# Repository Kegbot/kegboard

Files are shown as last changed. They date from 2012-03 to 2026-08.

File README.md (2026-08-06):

# Kegboard

Kegboard is the kegerator controller firmware from the [Kegbot][kegbot] project.
It reads flow meters, temperature sensors, and auth tokens, drives valves and
relays, and reports pours to a [Kegbot Server][kegbot-server].

This is **Kegboard v4**, a ground-up rewrite for **ESP32** built on
[ESPHome][esphome].

> **Looking for the Arduino version?** The v2/v3 firmware lives on the
> [`arduino`](https://github.com/Kegbot/kegboard/tree/arduino) branch. It is
> feature-frozen and does not speak the same protocol as this one.

**[📖 Documentation](https://docs.kegbot.org/projects/kegboard)** — overview,
operating modes, installation, wiring, configuration, and the protocol specs.
Sources in [`docs/`](docs/).

## What changed, and why

The old Kegboard was a dumb sensor pipe: it streamed raw tick counts over USB
serial, and a host daemon (`kegbot-pycore`) assembled those ticks into pours and
posted them to the server. That meant a cable, a always-on host, and a lost pour
whenever the host was down.

Kegboard v4 is a networked appliance:

- **Pours are assembled on the device.** The board detects the start and end
  of a pour, applies its own calibration, and reports a finished pour with an
  authoritative `volume_ml`.
- **One simple protocol.** Everything is JSON batches to a single endpoint
  (`POST /kegboard-event`), specified in
  [docs/kegboard-event-protocol.md](docs/kegboard-event-protocol.md) with
  normative JSON Schemas. Any server can implement it.
- **Outages are survivable.** Events queue and deliver late with correct
  timestamps — even on a board whose clock never synced — and retries can
  never create a duplicate drink.
- **No API keys to carry around.** An unprovisioned board shows up on the
  server dashboard by name; click allow and it provisions itself.
- **No `kegbot-pycore`, no USB cable.** WiFi and HTTP.
- **It's ESPHome.** Adding a display, a pressure sensor, a second thermometer,
  or a different RFID reader is YAML you write, not a firmware release we ship.

## Configuration

A minimal two-tap board reporting to a server:

```yaml
external_components:
  - source: github://Kegbot/kegboard@main

kegboard:
  id: kb

kegboard_meter:
  - id: flow0
    pin: GPIO4
    meter_number: 0
    total:
      name: Tap 1 Ticks
    pouring:
      name: Tap 1 Pouring

kegboard_reporter:
  reporting_url: !secret kegboard_reporting_url
  meters: [flow0]
```

See `examples/` for complete configs, and `boards/` for pin maps.

### `kegboard`

| Option | Default | Notes |
|---|---|---|
| `serial_number` | `kegboard-<mac>` | Device identity in the protocol. Set explicitly to adopt a replaced board's identity. |

### `kegboard_meter`

| Option | Default | Notes |
|---|---|---|
| `pin` | required | Meter input. Pulled up internally; counts falling edges. |
| `meter_number` | `0` | The protocol's meter number: `(device, meter_number)` identifies a tap server-side. Must be unique per meter (validated at build). The YAML `id` is a config-internal reference and is never reported. |
| `ml_per_tick` | `0.185` | SwissFlow SF800 and clones (~5.4 ticks/mL). The device's calibration is authoritative: reported volume comes from this. |
| `debounce` | `1200us` | Matches the legacy firmware's filter. |
| `idle_timeout` | `10s` | Silence after which a pour is considered finished. |
| `min_pour_ticks` | `3` | Anything shorter is treated as a drip and discarded. |
| `max_pour_duration` | `5min` | Safety cutoff for a stuck meter; `0s` disables. |
| `report_interval` | `250ms` | Throttle for sensor updates during a pour. |
| `series_resolution` | `100ms` | Bucket width for the diagnostic tick series; `0s` disables. |

Optional entities: `total`, `volume`, `flow_rate`, `pouring`.
Triggers: `on_pour_start`, `on_pour_end` (with `ticks`, `volume_ml`, `duration_ms`).
Actions: `kegboard_meter.reset_total`, `.end_pour`, `.set_calibration`.

### `kegboard_reporter`

Speaks the [Kegboard Event Protocol](docs/kegboard-event-protocol.md).

| Option | Default | Notes |
|---|---|---|
| `reporting_url` | required | Full URL, path included, e.g. `https://kegbot.example.com/api/kegboard-event`. No credential is configured — the device provisions its own bearer token by pairing via the server dashboard, and it persists in flash. |
| `meters` | `[]` | Meters whose pours are reported. |
| `relays` | `[]` | The device's numbered relays: `relay_number:` plus `relay:`. Reported in the `status` inventory, and the targets of server grants. |
| `thermo_sensors` | `[]` | `sensor:`/`name:` pairs; any ESPHome sensor works. |
| `heartbeat_interval` | `60s` | Status event cadence; also bounds worst-case command latency. |
| `pour_update_interval` | `1s` | Live `pour_update` cadence; `0s` disables. |
| `retry_interval` | `30s` | Base for exponential backoff, capped at 5 min. |

Optional diagnostic entities: `queue_depth`, `dropped`. A non-zero `dropped`
means events were lost and is worth alerting on.

### `kegboard_auth`

Applies [authenticated pouring](docs/authenticated-pouring.md):
server-decided grants driving valve relays and tagging pours for server-side
attribution. Requires a `kegboard_reporter`. (Serverless installs can gate
valves with plain ESPHome automations on the reader triggers instead.)

| Option | Default | Notes |
|---|---|---|
| `offline_policy` | `deny` | Token presented while the server is unreachable: `deny` (signal refusal), or `guest` (stay silent; pours proceed as guest pours). Neither opens valves. |
| `max_grant_duration` | `5min` | Device-side clamp on server-issued grants: the final bound on valve-open time. |

Actions: `kegboard_auth.token_attached` / `.token_detached` (`device`,
`token`), `.revoke`. Condition: `.is_authorized`. Triggers: `on_authorized`
(`auth_device`, `token`), `on_denied` (`reason`), `on_revoked`. Optional
entities: `authorized`.

### `kegboard_onewire`

iButton presence on a 1-Wire bus — ESPHome's `one_wire` enumerates devices but
has no arrive/leave events. Triggers `on_token_attached` and
`on_token_detached` with the ROM code as hex.

`max_missed_searches` (default `4`) is how many consecutive misses before a
detach is reported. A held iButton makes intermittent contact, so reporting on
the first miss would make it flap several times a second.

### Relays and buzzer

`packages/relays.yaml` and `packages/buzzer.yaml` are plain YAML over stock
components. The relay watchdog is worth keeping from the AVR firmware: a relay
left on is usually a valve held open, so each one switches itself off
`relay_watchdog_timeout` (default `10s`) after turning on. On grant-driven
relays, set it longer than `max_grant_duration` (the grant clamp is their
bound) or the watchdog closes the valve mid-grant.

## Repository layout

```
components/     ESPHome external components (this repo is the component source)
  kegboard/     Hub component + the framework-agnostic core (see CORE.md)
  kegboard_meter/     Flow meter and pour detection
  kegboard_reporter/  Event protocol client (batching, pairing, commands)
  kegboard_auth/      Per-meter authorization
  kegboard_onewire/   iButton presence
packages/       Composable YAML users include
boards/         Pin maps per target board
docs/           Manual + protocol specifications
schemas/        Normative JSON Schemas for the protocol
examples/       Worked configurations
tests/core/     Host unit tests -- plain g++, no hardware, no toolchain
script/         CI helpers
```

## Development

Host unit tests for the core logic need nothing but a C++ compiler:

```console
$ make -C tests/core
$ make -C tests/core STRICT=1   # warnings as errors, as CI runs it
```

Build output is scoped by OS and architecture (`build/Darwin-arm64/`, etc.), so
a checkout shared between a host and a container or VM won't hand one
platform's binaries to the other.

Formatting and lint mirror ESPHome's own conventions, since these components
compile into ESPHome's tree:

```console
$ pip install pre-commit && pre-commit install
$ pre-commit run --all-files
```

The manual is a Sphinx project in `docs/`, published at
[docs.kegbot.org/projects/kegboard](https://docs.kegbot.org/projects/kegboard).
Its toolchain is managed by [uv](https://docs.astral.sh/uv/), synced
automatically on first use:

```console
$ make -C docs html          # output in docs/_build/html/
$ make -C docs livehtml      # live-rebuild server while editing
```

## Simulator

`tools/kegboard-sim.py` is a TUI kegboard for developing receivers without
hardware. It speaks the full protocol — pairing, batching, `age_ms`,
commands, dedup — and validates every outgoing batch against the schemas, so
it cannot teach a server the wrong protocol.

```console
$ uv run tools/kegboard-sim.py http://localhost:8000/kegboard-event
```

Single keys drive it: pour a beer (with live `pour_update`s), toggle
temperature logging, present preset tokens (including an unknown fob and a
presence-style iButton), kill the heartbeat so your server's liveness check
can notice, go offline to build a backlog that delivers late with correct
ages, replay the last batch verbatim to exercise dedup, send an
unknown event type, and reboot to reset `boot_id`.

## Debugging

The reporter logs one line per delivery at `DEBUG` (status, event count,
bytes). To see the actual protocol traffic — every request and response body,
including `pour_update`s while beer is flowing — raise its log level to
`VERY_VERBOSE`:

```yaml
logger:
  logs:
    kegboard_reporter: VERY_VERBOSE
```

Then attach with `esphome logs <config>.yaml`. Two notes:

- `VERY_VERBOSE` lines are compiled out at default log levels, so production
  builds pay nothing for this machinery.
- The logger truncates lines to its buffer (default 512 bytes); a full batch
  body will clip. Add `logger: { tx_buffer_size: 2048 }` if that bites.

## Hardware notes

**ESP32 GPIOs are not 5 V tolerant.** Most beer flow meters are open-collector
hall-effect sensors, which are safe on a 3.3 V pull-up because they only ever
pull the line to ground. Meters with a push-pull 5 V output will damage the
ESP32 and need a level shifter or divider. Check your meter before wiring it.

## History

Kegboard was created in 2004 and has received several major updates over the
years:

- **v1 (2004)** — PIC16-based, written in the JAL programming language.
- **v2 (~2009)** — rewritten for Arduino, introducing the KBSP serial
  protocol.
- **v3 (2014)** — the Kegboard Pro Mini, a fully-assembled Arduino-based
  board.
- **v4 (2026)** — this ground-up ESP32 rewrite on ESPHome.

## License and copyright

Kegboard v4 is offered under the **MIT** license, matching the rest of the
Kegbot project; see `LICENSE.txt`.

Two notes on what that does and doesn't cover:

- **Built firmware images are GPLv3.** ESPHome's C++ runtime is GPLv3, and a
  compiled Kegboard image links against it. MIT is GPL-compatible, so this is
  fine and is how ESPHome external components normally work — but if you
  distribute binaries, you are distributing GPLv3 binaries. The source in this
  repository remains MIT and is reusable as such.
- **The `arduino` branch is still GPLv2-or-later.** The legacy AVR firmware was
  written under that license and had outside contributors; nothing here
  relicenses it.

Copyright 2003-2026 The Kegbot Project Contributors <info@kegbot.org>

[kegbot]: https://kegbot.org/
[kegbot-server]: https://github.com/Kegbot/kegbot-server
[esphome]: https://esphome.io/

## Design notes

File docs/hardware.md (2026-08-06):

# Hardware & Wiring

Kegboard v4 targets generic ESP32 devkits. There is no custom PCB (yet); the
legacy kegboard-mini/mega/coaster boards ran the AVR firmware and live on the
[`arduino` branch](https://github.com/Kegbot/kegboard/tree/arduino).

## Supported boards

| Board package | Chip | Notes |
|---|---|---|
| `boards/esp32-s3-devkitc-1.yaml` | ESP32-S3 | **Reference target.** Native USB (no adapter to flash), ample GPIO, PSRAM headroom. |
| `boards/esp32-devkit.yaml` | ESP32 (WROOM-32) | What most people already have in a drawer. |
| `boards/esp32-c6-devkitc-1.yaml` | ESP32-C6 | Forward-looking: WiFi 6, Thread/Zigbee radios. |

Other ESPHome-supported ESP32 variants work; write your own board package
with the same substitution names.

## Pin maps

Defined as substitutions in each board package; override them in your config
to relocate a peripheral.

| Substitution | S3 | Classic | C6 | Used by |
|---|---|---|---|---|
| `meter0_pin`–`meter3_pin` | 4–7 | 4, 5, 13, 14 | 4–7 | Flow meters |
| `onewire_pin` | 15 | 16 | 10 | Thermo 1-Wire bus |
| `relay0_pin`, `relay1_pin` | 16, 17 | 17, 18 | 11, 18 | Relays |
| `buzzer_pin` | 18 | 19 | 19 | Piezo buzzer |
| `led0_pin`, `led1_pin` | 8, 9 | 21, 22 | 20, 21 | Flow LEDs |
| `rfid_rx_pin` | 44 | 23 | 22 | RFID reader UART |
| `onewire_auth_pin` | 21 | 25 | 23 | iButton 1-Wire bus |

The maps avoid each chip's landmines: strapping pins, flash/PSRAM pins,
native-USB pins, and (on the classic ESP32) GPIO 34–39, which are input-only
with no internal pull-ups and so cannot bias an open-collector meter.

## Flow meters

Kegboard supports open-collector meters — typically hall-effect sensors that
pulse once per fixed volume as liquid passes. Meter inputs use the internal
pull-up and count falling edges; wire the meter's output straight to the pin,
its ground to ground.

> **ESP32 GPIOs are not 5 V tolerant.** Open-collector meters are safe on a
> 3.3 V pull-up even when powered from 5 V, because they only ever pull the
> line to ground. Meters with a push-pull 5 V output will damage the ESP32
> and need a level shifter or divider. Check your meter before wiring it.

The default calibration (`ml_per_tick: 0.185`, ~5.4 ticks/mL) matches the
SwissFlow SF800 and its clones. Other meters work; set `ml_per_tick`
accordingly (a Vision 2000 is ~2200 ticks/L → `0.4545`).

## Temperature sensors

DS18B20/DS18S20 sensors on the `onewire_pin` bus, via ESPHome's `one_wire`
and `dallas_temp`. Any number of sensors on one bus; each needs the usual
4.7 kΩ pull-up to 3.3 V (many breakout probes include it).

## Authentication readers

- **125 kHz RFID:** RDM6300-class readers (the ID-12 lineage) on
  `rfid_rx_pin` via UART at 9600 baud, using ESPHome's `rdm6300`. TX-only —
  nothing is wired back to the reader.
- **iButton:** a second 1-Wire bus on `onewire_auth_pin`, read by
  `kegboard_onewire`. Kept separate from the thermo bus so a wet hand stays
  away from the keg sensors.
- **Anything else:** any ESPHome reader (`wiegand`, `pn532`, `rc522`, ...)
  can feed `kegboard_auth` — see
  [extending](developer-notes.md#extending-a-board).

## Relays and valves

`packages/relays.yaml` defines two GPIO relay outputs, each with a watchdog
that switches it off `relay_watchdog_timeout` (default 10 s) after it turns
on — see the package's notes before putting a grant-driven valve on one.
Use a relay module rated for logic-level (3.3 V) input, or a
transistor driver. What's downstream is usually a solenoid valve; give it its
own supply and a flyback diode if the module lacks one.

## Buzzer and LEDs

A **passive** piezo on `buzzer_pin` plays the legacy Kegboard melodies
(`packages/buzzer.yaml`); an active buzzer generates its own tone and will
ignore them. Flow LEDs are ordinary GPIO LEDs with resistors, wired per the
pin map and driven from `on_pour_start`/`on_pour_end` automations.

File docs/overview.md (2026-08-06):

# Kegboard Overview

## What is a Kegboard?

*Kegboard* is the controller board in a [Kegbot](https://kegbot.org/) system.
It's the device that monitors flow meters and publishes this data to a system
like [Kegbot Backend](https://github.com/kegbot/kegbot-backend).

A kegboard can also monitor additional, optional accessories like temperature sensors
and OneWire-based authentication devices; and it can drive valves,
relays, and buzzers.

An open source Kegboard project has existed since around 2005. Today, it is
built for esp32-based devices, and leverages the [ESPHome](https://esphome.io/)
framework.

You can flash this firmware to a device and use it in standalone mode, or
point it at a [Kegbot Server](https://github.com/Kegbot/kegbot-server) instance
for full functionality.

## Features

- **Flow sensing.** Any number of meters, limited only by GPIO. Pour
  detection runs on the device: start, end, volume, flow rate, and a
  diagnostic tick time series per pour.
- **On-device calibration.** `ml_per_tick` lives on the board; reported
  volumes are authoritative.
- **Temperature sensing.** DS18B20/DS18S20 sensors on a 1-Wire bus, any
  number of them, via ESPHome's stock `dallas_temp`.
- **Authentication.** 125 kHz RFID readers and iButtons out of the box; any
  reader ESPHome supports can feed the auth component.
- **Authenticated pouring.** Server-decided grants drive valve relays and
  pour attribution. See
  [Authenticated Pouring](authenticated-pouring.md).
- **Relay control with watchdog.** Each relay switches itself off after a
  timeout, so a crashed controller never leaves a valve open; grant-held
  relays are bounded by the grant clamp instead.
- **Buzzer.** The classic Kegboard melodies, transcribed from the AVR
  firmware.
- **Outage-proof reporting.** Events queue on the device and deliver late
  with correct timestamps; retries can never create a duplicate drink.
- **Dashboard pairing.** No API keys: an unprovisioned board appears on the
  server dashboard by name and provisions itself when approved.
- **Home Assistant, free.** Every meter, sensor, and relay is an ESPHome
  entity; a server is optional.
- **Open protocol.** Everything is JSON to a single HTTP endpoint, specified
  in the [Kegboard Event Protocol](kegboard-event-protocol.md) with normative
  schemas. Any server can implement it.

Everything is optional except a meter. A board with no thermo sensor, no
reader, and no server still meters pours.

## Requirements

- **An ESP32 board.** Any ESPHome-supported variant works; tested pin maps
  ship for the ESP32-S3-DevKitC-1 (reference), the classic ESP32 DevKitC, and
  the ESP32-C6-DevKitC-1. See [Hardware & Wiring](hardware.md).
- **Flow meters.** Open-collector hall-effect meters such as the SwissFlow
  SF800. **ESP32 GPIOs are not 5 V tolerant** — see the
  [hardware notes](hardware.md#flow-meters).
- **WiFi.**
- **ESPHome** to build and flash, until prebuilt binaries ship. See
  [Installation](installation.md).
- Optionally, a **[Kegbot Server](https://github.com/Kegbot/kegbot-server)**
  (or anything else implementing the event protocol) to record drinks.

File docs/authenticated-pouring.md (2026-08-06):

# Authenticated Pouring

How a token presented at a Kegboard becomes an open valve and an attributed
pour. This document specifies the interaction between device and server; the
message envelopes it uses (`token` events, commands, `command_result`) are
defined in the main protocol doc.

## 1. Background

A Kegboard install always has flow meters on its beer lines: every pour is
measured, whether or not anyone is identified. Many installs add more, per
tap: a solenoid valve on a relay, so beer only flows for someone
authorized, and a token reader nearby (RFID, iButton, ...) to identify who
that is. Others have no valves at all — anyone can pour at any time, and
authentication only decides who a pour is attributed to.

**Everything in this document is optional.** A monitoring-only Kegboard —
just meters, no readers, no valves — needs none of it: it simply reports
guest pours, and its config never mentions authentication at all.

A presented token means something — which user, which taps, how much — and
the token→user database that answers this can be large. It lives on the
server; the valves and the pour detection live on the device. This doc
defines who decides what, and how the two sides stay simple.

## 2. Summary

- A **pour** is metered flow, reported to the server as an event
  (main doc §5.1) — authenticated or not.
- A **grant** is permission to pour. The server creates one with an
  `authorize` command, naming the meters it covers, the relays (valves) it
  opens, and its limits: max volume, max total time, max idle time. One
  active grant per meter.
- Presenting a physical auth token sends a `token` event to the server.
  In response, the server decides whether to grant access (`authorize`
  command), opening any relevant valves; or to deny it (`deny` command).
- Pours are tagged with the covering grant's id; the server maps that to a
  user. **Identity never reaches the device.**
- A grant ends when a limit is hit, its token detaches, the server revokes
  it, or a newer grant takes its meters. Every ending is reported as a
  `grant_end` event with its reason.
- Server unreachable? A configured offline policy (§6) decides whether the
  user is signaled a refusal — either way, nothing opens, and the queued
  `token` event preserves the audit trail.

The rest of this doc unpacks each of these.

## 3. Authorization modes

An install is either authenticated or open:

| Mode | Who decides | Needs server online? | Use case |
|---|---|---|---|
| authenticated (`kegboard_auth` configured) | Server, per token presentment | Yes (with a configurable offline fallback) | Gated or attributed taps. Scales to any token database; policy lives in one place. |
| `open` (no auth component) | Nobody — no gating | No | Meters-only installs, no valves. Every pour is a guest pour. |

Authorization always means the server decides. A serverless install that
wants token-driven valves can wire the reader triggers to relay switches
with plain ESPHome automations — outside this protocol entirely.

The device is **stateless about policy**: it holds no token database and
no meter↔relay map — only the currently active grant(s), each of which
arrives naming the meters it covers and the relays it opens (see main doc
§7.1). The meter↔relay association is backend configuration, owned in
exactly one place: the server composes each grant's sets from it, and the
device applies them verbatim.

## 4. The core flow

1. **Token presented.** The reader reports a token; the device emits a
   `token` event with `action: "attached"` — always a question for the
   server. The device flushes the batch immediately.
2. **Server decides.** The server looks up the token, applies whatever
   policy it likes (user standing, keg access, time of day), and responds —
   in the same HTTP response — with an `authorize` or a `deny` command.
   Servers SHOULD always answer a decision-requesting token event with one
   of the two.
3. **Device acts.** On `authorize`, the device opens the relays named in
   the grant, tags subsequent pours on the granted meters with the
   grant, and acknowledges with a `command_result` event. On `deny`, the
   tap stays closed and the device SHOULD signal the user (e.g. a refusal
   tone). If the response carries neither — a server bug, defensively —
   the device treats the presentment as denied, without the user signal.
4. **Grant ends** by whichever comes first: token detach (presence
   readers), any of the grant's limits — volume poured, total time, idle
   time — being reached, or a server `deauthorize` command. The device
   closes the valve, ends any in-flight pour (still tagged with the
   departing grant), clears the grant, and reports a `grant_end` event
   naming the reason (main doc §5.7), so the server never has to guess
   why a tap went cold.

Identity never travels down. The server attributes the resulting pours
itself, from each pour's `grant_id` — the server's own identifier for the
grant (main doc §5.1, §7.1). The device acts on tokens and grants; it
never knows who a user is.

Authorization latency is one HTTP round trip, because the decision rides the
response to the token event itself:

```
reader              device                                server
  |                   |                                     |
  | token 0089f2c4    |                                     |
  |------------------>| POST /kegboard-event                |
  |                   |   [token attached] ---------------->|
  |                   |                                     | lookup, policy
  |                   |        200 {commands:[authorize]}   |
  |                   |<------------------------------------|
  |                   | open valve(s), record grant         |
  |                   |                                     |
  |                   | ...pour happens...                  |
  |                   | POST [pour grant_id=g_1,            |
  |                   |       command_result ok] ---------->|
```

## 5. Commands

The three commands this flow uses are fully specified in the main protocol
doc (§7.1–7.3); this section describes only their role in the flow.

- **`authorize`** carries exactly one grant: a server-assigned id, the
  meters it covers and the relays it opens (if any). The server composes
  these sets from its own meter and relay configuration, and any limits. The device
  applies it verbatim: relays open, and pours on the granted meters are
  tagged with the grant, until a limit (volume, total time, idle time) or
  the device's own clamp ends it. Several grants at once — different
  taps, different policy — are simply several `authorize` commands in
  one response.
- **`deny`** is the explicit refusal: the device signals the user, and no
  state changes.
- **`deauthorize`** is a server-initiated cutoff, revoking grants by
  id — an admin button, a policy engine, an emergency stop. Detach and
  the grant's own limits do the same thing device-side without a
  command.

## 6. Offline behavior

The decision-maker being remote means presentment can race an outage. The
device applies a configured `offline_policy` when a token event cannot be
delivered (network error / 5xx / no response before a short timeout,
suggested 5 s):

| `offline_policy` | Behavior |
|---|---|
| `deny` (default) | Tap stays closed; the device signals refusal. Correct for installs where gating is the point. |
| `guest` | **Nothing opens and nothing is granted** — the only difference from `deny` is that the user is not signaled a refusal. Pours proceed as ordinary guest pours (a meter without a valve meters regardless), and the queued `token` event reaches the server later, preserving the audit trail. Opening valves offline may be revisited later; for now an offline server never results in an opened valve. |

Note what is deliberately absent: a device-side token cache. Caching
assignments would reintroduce the state this design removes and creates
stale-revocation problems.

## 7. Multi-meter, multi-user

Grants are per meter, so a two-tap device can simultaneously have Alice on
meter 0 and Bob on meter 1:

- Alice presents; the server responds
  `authorize {grant_id: "g_1", meter_numbers: [0], relay_numbers: [0], ...}`,
  recording `g_1` as Alice's.
- Bob presents; the server responds
  `authorize {grant_id: "g_2", meter_numbers: [1], relay_numbers: [1], ...}`,
  recording `g_2` as Bob's.
- Each meter's pours arrive tagged with their own grant's `grant_id`, so
  the server attributes meter 0's pours to Alice and meter 1's to Bob.
  Detach, limits, and `deauthorize` affect only their own grant's meters.

Which meter a presentment maps to is **server policy**, not protocol. The
`token` event tells the server which reader saw the token (`auth_device`);
an install with one reader per tap can name readers accordingly (e.g.
`core.rfid.0`) and the server maps reader → meter. An install with one
shared reader can grant all meters, or apply fancier policy (the user's
reserved tap, the tap with their keg on it). The protocol only carries the
outcome: each grant's `meter_numbers` and `relay_numbers`.

## 8. Grant and pour corner cases

Every way a pour and a grant can interact, and the rule for each. Two
principles cover them all:

- **Attribution is decided when the pour ends.** The pour is tagged
  (`auth_device`, `auth_token`, `grant_id` — main doc §5.1) with the grant
  covering its meter at that moment, in full. The server resolves the user
  from `grant_id` — pinned to its own authorization decision, so a
  late-delivered pour attributes correctly even if the token was reassigned
  in the meantime.
- **Limit accounting is decided as flow is observed.** Flow counts toward
  the grant covering the meter at the moment it flows — toward its
  `max_volume_ml`, and resetting its `max_idle_ms` — and is never
  retroactive.

Where the two disagree (case 2 below), that is deliberate: the rules stay
simple, and the mismatch is confined to a corner. In general this catalog
favors the simple implementation over the clever one, accepting that a
handful of corner cases do slightly surprising things.

1. **Pour with no grant.** An unauthenticated guest pour: no auth fields
   at all. This is every pour in `open` mode, and any pour on a meter
   nobody has authorized — installs without valves meter everything, all
   the time.
2. **Grant arrives mid-pour: it adopts the pour.** The pour keeps its
   `pour_id` and, at its end, is attributed to the grant **in full**,
   including the volume poured before the grant arrived. This is the
   headline corner case on valve-less installs: someone starts pouring,
   realizes they forgot to authenticate, and keys in mid-glass — the whole
   glass lands on their tab. Per the second principle, the pre-grant
   volume does *not* count toward the grant's limits. Adoption is a
   single, clearly marked policy point in the firmware, so it can become
   "split into a new pour" later without disturbing anything else.
3. **Grant replaces another mid-pour: the pour splits.** The in-flight
   pour ends immediately, tagged with the departing grant; flow that
   continues opens a new pour (fresh `pour_id`) under the new grant. Pour
   boundaries always align with authorization boundaries, so consecutive
   drinkers never share a pour record.
4. **Grant updated (same `grant_id`) mid-pour: nothing happens.** It is
   the same grant; the pour continues under it, counters intact.
5. **Grant ends mid-pour** — limit reached, token detached, `deauthorize`:
   the pour ends first, tagged with the grant, and its event precedes the
   `grant_end` (main doc §5.7). Flow that continues — after the valve
   closes, or on a meter that never had one — is case 1 again: a new,
   unauthenticated guest pour.

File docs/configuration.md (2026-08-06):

# Configuration Reference

Kegboard is configured in ESPHome YAML. This chapter covers the Kegboard
components; everything else (WiFi, sensors, displays, automations) is stock
ESPHome — see [esphome.io](https://esphome.io/). `examples/` has complete
configs; `packages/` has the composable pieces.

```yaml
external_components:
  - source: github://Kegbot/kegboard@main
```

## `kegboard`

The hub. Required by every other component.

| Option | Default | Notes |
|---|---|---|
| `serial_number` | `kegboard-<mac>` | Device identity in the protocol. Set explicitly to adopt a replaced board's identity. |

## `kegboard_meter`

One entry per flow meter.

```yaml
kegboard_meter:
  - id: flow0
    pin: GPIO4
    meter_number: 0
    total:
      name: Tap 1 Ticks
    pouring:
      name: Tap 1 Pouring
```

| Option | Default | Notes |
|---|---|---|
| `pin` | required | Meter input. Pulled up internally; counts falling edges. |
| `meter_number` | `0` | The protocol's meter number: `(device, meter_number)` identifies a tap server-side. Must be unique per meter (validated at build). The YAML `id` is a config-internal reference and is never reported. |
| `ml_per_tick` | `0.185` | SwissFlow SF800 and clones (~5.4 ticks/mL). The device's calibration is authoritative: reported volume comes from this. |
| `debounce` | `1200us` | Matches the legacy firmware's filter. |
| `idle_timeout` | `10s` | Silence after which a pour is considered finished. |
| `min_pour_ticks` | `3` | Anything shorter is treated as a drip and discarded. |
| `max_pour_duration` | `5min` | Safety cutoff for a stuck meter; `0s` disables. |
| `report_interval` | `250ms` | Throttle for sensor updates during a pour. |
| `series_resolution` | `100ms` | Bucket width for the diagnostic tick series; `0s` disables. |

Optional entities: `total`, `volume`, `flow_rate`, `pouring`.
Triggers: `on_pour_start`, `on_pour_end` (with `ticks`, `volume_ml`,
`duration_ms`).
Actions: `kegboard_meter.reset_total`, `.end_pour`, `.set_calibration`.

## `kegboard_reporter`

Speaks the [Kegboard Event Protocol](kegboard-event-protocol.md) to a server.

| Option | Default | Notes |
|---|---|---|
| `reporting_url` | required | Full URL, path included, e.g. `https://kegbot.example.com/api/kegboard-event`. No credential is configured — the device provisions its own bearer token by pairing via the server dashboard, and it persists in flash. |
| `meters` | `[]` | Meters whose pours are reported. |
| `relays` | `[]` | The device's numbered relays: `relay_number:` plus `relay:` (the relay to drive, e.g. from `packages/relays.yaml`). Reported in the `status` inventory, and the targets of server grants (and of `set_relay`, once that reserved command is specified). |
| `thermo_sensors` | `[]` | `sensor:`/`name:` pairs; any ESPHome sensor works. |
| `heartbeat_interval` | `60s` | Status event cadence; also bounds worst-case command latency. |
| `pour_update_interval` | `1s` | Live `pour_update` cadence; `0s` disables. |
| `retry_interval` | `30s` | Base for exponential backoff, capped at 5 min. |

Optional diagnostic entities: `queue_depth`, `dropped`. A non-zero `dropped`
means events were lost and is worth alerting on.

## `kegboard_auth`

Applies [authenticated pouring](authenticated-pouring.md): server-decided
grants driving valve relays and tagging pours for server-side attribution.
Requires a `kegboard_reporter`. (Serverless installs can gate valves with
plain ESPHome automations on the reader triggers instead.)

| Option | Default | Notes |
|---|---|---|
| `offline_policy` | `deny` | Token presented while the server is unreachable: `deny` (signal refusal), or `guest` (stay silent; pours proceed as guest pours). Neither opens valves. |
| `max_grant_duration` | `5min` | Device-side clamp on server-issued grants: the final bound on valve-open time. |

Actions: `kegboard_auth.token_attached` / `.token_detached` (`device`,
`token`), `.revoke`. Condition: `.is_authorized`. Triggers: `on_authorized`
(`auth_device`, `token`), `on_denied` (`reason`), `on_revoked`. Optional
entities: `authorized`.

Readers feed it through the actions — see `examples/kegbot-full.yaml` for
RFID and iButton wiring.

## `kegboard_onewire`

iButton presence on a 1-Wire bus — ESPHome's `one_wire` enumerates devices
but has no arrive/leave events. Triggers `on_token_attached` and
`on_token_detached` with the ROM code as hex.

| Option | Default | Notes |
|---|---|---|
| `one_wire_id` | auto | The bus to poll; bound automatically when exactly one `one_wire` bus exists, required with several. Use a bus separate from the thermo sensors. |
| `update_interval` | `1s` | Poll cadence. |
| `max_missed_searches` | `4` | Consecutive misses before a detach is reported. A held iButton makes intermittent contact; reporting on the first miss would flap several times a second. |

## Packages

Plain YAML over stock components; include what you have.

| Package | Provides |
|---|---|
| `packages/base.yaml` | WiFi + fallback AP, OTA, logging, native API, SNTP time, HTTP client. Expects `name` and `friendly_name` substitutions. |
| `packages/relays.yaml` | Two GPIO relays, each with a watchdog: auto-off after `relay_watchdog_timeout` from the on-edge (default `10s`, `0s` disables). On grant-driven relays set it longer than `max_grant_duration` — the grant clamp is their bound — or the watchdog closes the valve mid-grant. |
| `packages/buzzer.yaml` | Passive piezo via `rtttl`, with the legacy boot/auth/ping melodies as scripts. |
| `boards/*.yaml` | Chip selection + pin-map substitutions. See [Hardware & Wiring](hardware.md). |

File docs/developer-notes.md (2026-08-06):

# Developer Notes

## Repository layout

```
components/     ESPHome external components (this repo is the component source)
  kegboard/     Hub component + the framework-agnostic core (see CORE.md)
  kegboard_meter/     Flow meter and pour detection
  kegboard_reporter/  Event protocol client (batching, pairing, commands)
  kegboard_auth/      Per-meter authorization
  kegboard_onewire/   iButton presence
packages/       Composable YAML users include
boards/         Pin maps per target board
docs/           This manual + protocol specifications
schemas/        Normative JSON Schemas for the protocol
examples/       Worked configurations
tests/core/     Host unit tests — plain g++, no hardware, no toolchain
tools/          kegboard-sim, the TUI simulator
script/         CI helpers
```

## Building and testing

Host unit tests for the core logic need nothing but a C++ compiler:

```console
$ make -C tests/core
$ make -C tests/core STRICT=1   # warnings as errors, as CI runs it
```

Firmware builds are plain ESPHome:

```console
$ esphome compile examples/kegbot-2tap.yaml
```

Formatting and lint mirror ESPHome's conventions (clang-format, ruff,
yamllint), since these components compile into ESPHome's tree:

```console
$ pip install pre-commit && pre-commit install
$ pre-commit run --all-files
```

## Hacking on the core

The rules, enforced by CI (`script/check-core-purity.py`):

1. Core files (`components/kegboard/*.cpp/h` in the `kbcore` namespace)
   include only the C++ standard library — no ESPHome, Arduino, or ESP-IDF
   headers.
2. No I/O, no clocks, no timers; time is passed in as arguments.
3. Every core file has host tests in `tests/core/`.

This is what keeps pour detection, the grant table, and the queue-and-retry
path testable in milliseconds without flashing a board — and what keeps the
ESPHome components thin enough to port away from ESPHome if that ever becomes
necessary. Details in
[`components/kegboard/CORE.md`](https://github.com/Kegbot/kegboard/blob/main/components/kegboard/CORE.md).

`script/check-events-schema.py` keeps the C++ event serializers and the JSON
Schemas in agreement.

## Extending a board

Most extensions are YAML, not firmware:

- **More taps:** another `kegboard_meter` entry with a fresh `meter_number`.
- **A different reader:** any ESPHome reader component whose trigger calls
  `kegboard_auth.token_attached` with a `device` name and token string. The
  string must match how the token is registered server-side — log the first
  scan and register that exact value. `examples/kegbot-full.yaml` shows RFID
  (`rdm6300`) and iButton (`kegboard_onewire`).
- **Displays, pressure sensors, more relays, anything ESPHome supports:**
  stock components alongside the Kegboard ones; `on_pour_*` triggers and the
  `pouring`/`authorized` entities are the integration points.

## The simulator

`tools/kegboard-sim.py` is a TUI kegboard for developing receivers without
hardware. It speaks the full protocol — pairing, batching, `age_ms`,
commands, dedup — and validates every outgoing batch against the schemas, so
it cannot teach a server the wrong protocol.

```console
$ uv run tools/kegboard-sim.py http://localhost:8000/kegboard-event
```

Single keys pour a beer (with live `pour_update`s), toggle temperature
logging, present preset tokens, kill the heartbeat, go offline to build a
backlog that delivers late, replay the last batch to exercise dedup, send an
unknown event type, and reboot to reset `boot_id`.

## Protocol traffic logging

The reporter logs one line per delivery at `DEBUG`. For full request and
response bodies:

```yaml
logger:
  logs:
    kegboard_reporter: VERY_VERBOSE
```

`VERY_VERBOSE` lines are compiled out at default log levels, so production
builds pay nothing. The logger truncates lines to its buffer (default 512
bytes); add `logger: { tx_buffer_size: 2048 }` if a batch body clips.

## Cutting a release

The canonical firmware version is `KEGBOARD_VERSION` in
`components/kegboard/kegboard.cpp`; `docs/conf.py` and `packages/base.yaml`
mirror it and must always agree. Don't edit them by hand — release with:

```console
$ script/bump.py --dry-run   # preview
$ script/bump.py             # 4.0.1 -> 4.0.2; a -pre/-dev suffix is dropped
$ script/bump.py 4.1.0       # or pick the version explicitly
```

`bump.py` verifies the tree is clean and the tag is free, updates all three
version files, dates the changelog's "Current version (in development)"
section as `## vX.Y.Z (YYYY-MM-DD)` (leaving a fresh open section above it),
commits, and creates the `vX.Y.Z` tag. It does not push; publish with:

```console
$ git push origin HEAD vX.Y.Z
```

## Protocol changes

The [event protocol](kegboard-event-protocol.md) and
[authenticated pouring](authenticated-pouring.md) docs are the contract, and
the schemas in `schemas/` are normative. Changing the wire format means
updating the spec, the schemas, the core serializers, the simulator, and the
schema-agreement check together.

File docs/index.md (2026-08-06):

# Kegboard Manual

This is the manual for **Kegboard**, the ESP32-based hardware controller for a [Kegbot](https://kegbot.org/).

```{toctree}
:caption: Kegboard Manual
:maxdepth: 1

overview
operating-modes
installation
hardware
configuration
operation
developer-notes
changelog
```

```{toctree}
:caption: "Appendix"
:maxdepth: 1

kegboard-event-protocol
authenticated-pouring
```

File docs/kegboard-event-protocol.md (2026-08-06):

# Kegboard Event Protocol

**Version:** 1

The protocol a Kegboard controller uses to talk to a server.

Companion document: [Authenticated Pouring](authenticated-pouring.md), which
specifies how token presentment, server-side authorization, and valve control
compose on top of this protocol.

## 1. Protocol Goals

- **One endpoint, one document schema.** A third party should be able to receive
  Kegboard data by implementing a single HTTP handler against a single JSON
  Schema. This document plus the schemas is the whole contract.
- **The device is authoritative for volume.** Calibration (`ml_per_tick`)
  lives on the controller. Reports always carry `volume_ml`. Raw meter
  values ("ticks") may be reported, but only as diagnostic values.
- **Outage-proof.** Events queue on the device and deliver late with correct
  timestamps, without requiring the device to have a synchronized clock.
- **Exactly-once effect.** Delivery is at-least-once; event ids make
  processing idempotent, so a retry can never create a duplicate drink.
- **Simple authentication.** Devices stream data to endpoint that may optionally
  require authentication. A simple pairing protocol makes it happen.
- **Transport-portable.** The envelope is defined over HTTP here, but carries
  no HTTP-isms in the body, so the same messages can later ride MQTT, BLE, or
  WebSocket unchanged.

## 2. Transport

```
POST {reporting_url}
Authorization: Bearer <token>
Content-Type: application/json
```

- The reporting URL — path included — is device configuration, used verbatim;
  the device attaches no meaning to it. Servers SHOULD expose the endpoint at
  a stable, documented path such as `/kegboard-event`.
- The request body is a single JSON object (§3); the response body is a
  single JSON object (§7).
- Maximum request body size a server must accept: **16 KiB**. The device
  bounds itself well under this.

### Authentication

Authentication is optional, and the server drives it:

- A device holding a bearer token sends `Authorization: Bearer <token>` on
  every request. A device without one sends **no `Authorization` header at
  all** — there is no placeholder, no empty header, no handshake.
- A server MAY simply accept (2xx) unauthenticated batches. The device then
  never pairs and never holds a token. This is deliberate: the minimum
  viable receiver is a single unauthenticated HTTP handler with no auth
  machinery whatsoever.
- **Only a 401 introduces authentication.** A 401 tells the device this
  server wants a credential, sending it into pairing (§8); once provisioned,
  every subsequent request carries the header. The same 401 later serves as
  revocation — the device drops its token and re-pairs.
- TLS is strongly recommended whenever tokens are in play; the token is a
  plain bearer credential.

### Status-code semantics

The device keys its queue behavior on the status code:

| Status | Device behavior |
|---|---|
| 2xx | Batch accepted (or safely deduplicated). Remove events from queue. Process response body (§7). |
| 401 | Not authorized. Keep events queued; enter/continue pairing (§8). |
| other 4xx | Batch can never succeed (malformed, unsupported version). Drop the batch, surface an error diagnostic. |
| 5xx / network error / timeout | Transient. Keep events queued, retry with exponential backoff. |

A server that accepts a batch MUST have durably processed (or deduplicated)
every event in it before returning 2xx. There is no partial acceptance: if a
server cannot process one event in a batch, it either drops that event
internally (and still returns 2xx) or fails the whole batch with 5xx. This
keeps device logic trivial.

## 3. Request envelope

```json
{
  "v": 1,
  "device": "kegboard-a1b2c3",
  "boot_id": "9f3a2c1b",
  "sent_uptime_ms": 8123456,
  "events": [ ... ]
}
```

| Field | Type | Req | Description |
|---|---|---|---|
| `v` | integer | yes | Protocol version. This document describes `1`. |
| `device` | string | yes | Stable device identity, e.g. `kegboard-a1b2c3`. Derived from MAC by default, user-overridable. |
| `boot_id` | string | yes | Opaque id regenerated each boot (e.g. 8 hex chars). Scopes sequence numbers so they need not survive reboot. |
| `sent_uptime_ms` | integer | yes | Device uptime when this request was serialized. Diagnostic. |
| `events` | array | yes | 1–16 events, oldest first. |

## 4. Event envelope

Every element of `events`:

```json
{
  "id": 42,
  "type": "pour",
  "age_ms": 4200,
  "time": "2026-08-03T18:02:11Z",
  "data": { ... }
}
```

| Field | Type | Req | Description |
|---|---|---|---|
| `id` | integer | yes | Sequence number, monotonically increasing per boot, starting at 1. `(device, boot_id, id)` is the global dedup key. |
| `type` | string | yes | One of §5's types. Servers MUST ignore (but still 2xx) unknown types. |
| `age_ms` | integer | yes | How long before serialization the event occurred. Recomputed at every (re)send. **This is the authoritative time signal**; see §6. |
| `time` | string (RFC 3339) | no | Wall time of the event, present only if the device clock was synchronized when the event occurred. Informational. |
| `data` | object | yes | Type-specific payload. |

> **Why event ids are boot-scoped integers while `pour_id` (§5.1) is a
> globally unique string:** event ids are transport bookkeeping — consumed
> once at ingest for dedup and ordering, then never referenced again — so a
> composed key is fine and a per-event UUID would spend 36 bytes on every
> heartbeat and temperature reading for no benefit. Pours are domain objects
> that outlive the transport (they become database rows, URLs, log lines), so
> they carry an identifier that is unique as-is, with nothing to compose and
> nothing to get wrong.

## 5. Event types

### 5.1 `pour`

A completed pour: the durable record. Emitted once, when the pour ends.

Like every event, a pour is timed by the envelope's `age_ms` (§4, §6) — there
is no separate timestamp in the payload, and queued pours delivered late keep
correct timing automatically. The anchor is the **end of the pour**: the
event is created the moment the pour finishes, so
`pour_end = server_now - age_ms`, and the start is `pour_end - duration_ms`.

```json
{
  "meter_number": 0,
  "pour_id": "5f8e2c34-9d1b-4a7e-b02c-8f13d9a6e415",
  "volume_ml": 355.2,
  "duration_ms": 7100,
  "auth_device": "core.rfid",
  "auth_token": "0089f2c4",
  "grant_id": "g_5501",
  "ticks": 1919,
  "ml_per_tick": 0.185,
  "tick_series": "0:3 100:14 200:31"
}
```

| Field | Type | Req | Description |
|---|---|---|---|
| `meter_number` | integer | yes | Meter number on this device, 0-based. `(device, meter_number)` identifies a tap server-side. |
| `pour_id` | string | yes | Globally unique, **opaque** pour identifier; see §5.2. |
| `volume_ml` | number | yes | Poured volume. **Authoritative.** Computed on-device from its own calibration. |
| `duration_ms` | integer | yes | First tick to last tick. |
| `auth_device` | string | no | Reader that authorized the pour (`core.rfid`, `onewire`, ...). |
| `auth_token` | string | no | Token that authorized the pour. |
| `grant_id` | string | no | The server-assigned id of the grant that covered this pour (§7.1). Absent for ungated (guest) pours. |
| `ticks` | integer | no | Raw tick count. Advisory diagnostic only; servers MUST NOT compute volume from it. |
| `ml_per_tick` | number | no | Calibration in effect when the pour ended. Diagnostic; lets a server sanity-check `ticks * ml_per_tick ≈ volume_ml`. |
| `tick_series` | string | no | Space-separated `<offset_ms>:<ticks>` pairs. Diagnostic. |

There is no user field: **the device never learns identity**. The server
attributes a pour from `grant_id` — which pins it to the server's own
authorization decision, and so stays correct even if the token is reassigned
between the pour and a late queued delivery. A pour without one is a guest
pour.

### 5.2 `pour_update`

A pour in progress: the live view. Lets a server UI render an odometer while
beer is flowing. Emitted at most every `pour_update_ms` (device-tunable,
default 1000; `0` disables) from pour start until the final `pour` event.

```json
{
  "meter_number": 0,
  "pour_id": "5f8e2c34-9d1b-4a7e-b02c-8f13d9a6e415",
  "volume_ml": 120.4,
  "duration_ms": 2400
}
```

| Field | Type | Req | Description |
|---|---|---|---|
| `meter_number` | integer | yes | Meter number. |
| `pour_id` | string | yes | Identifies the pour: all updates of one pour and its final `pour` event carry the same value. **Opaque and globally unique** — the device currently generates a UUIDv4, but clients MUST NOT validate the format; it may change. Usable as-is as a key, with no device/boot qualifiers. |
| `volume_ml` | number | yes | Volume so far. |
| `duration_ms` | integer | yes | Elapsed since first tick. |

There is no rate field: flow rate is derivable (`volume_ml / duration_ms`, or
better, the delta between successive updates), and the protocol does not
carry what a receiver can compute.

**`pour_update` is best-effort and ephemeral**, and is the one exception to
§9's delivery guarantees: the device sends updates only when the connection
is healthy, silently discards them rather than queueing on failure, and their
loss does not count toward `events_dropped`. Servers MUST NOT treat updates
as authoritative — the final `pour` event is the record, and a server
receiving updates but no final `pour` (device rebooted mid-pour) must not
synthesize a drink from them.

### 5.3 `temperature`

A sensor reading. Emitted at the device's configured interval.

```json
{ "sensor": "thermo-28ff641d8fbb0517", "temp_c": 4.25 }
```

| Field | Type | Req | Description |
|---|---|---|---|
| `sensor` | string | yes | Device-scoped sensor name. |
| `temp_c` | number | yes | Degrees Celsius. |

### 5.4 `token`

An auth token arrived or left. Central to server-side authorization; see the
[Authenticated Pouring](authenticated-pouring.md) doc for the full flow.

```json
{
  "auth_device": "onewire",
  "token": "0000000012345678",
  "action": "attached"
}
```

| Field | Type | Req | Description |
|---|---|---|---|
| `auth_device` | string | yes | Reader name (`core.rfid`, `onewire`, ...). |
| `token` | string | yes | Token value, lowercase hex by convention. |
| `action` | string | yes | `attached` or `detached`. |

An `attached` event is always a question: the server decides, and its
answer — an `authorize` or `deny` command — rides the same response (see
companion doc).

The device SHOULD flush a batch immediately when a token is attached, since
authorization latency is the user standing at the tap waiting.

### 5.5 `status`

Device health and configuration. Emitted at boot and then at the heartbeat
interval (default **1 minute**). Also the vehicle for making data loss
visible, for letting the server discover device settings it cannot set,
and for self-describing the device's hardware: `meters` and `relays` are
**exhaustive inventories**, so a server can allocate its records for every
port automatically — and retire records for ports that stop being reported.

```json
{
  "state": "boot",
  "fw_version": "4.0.0",
  "uptime_ms": 12345,
  "wifi_rssi_dbm": -61,
  "events_dropped": 0,
  "config": {
    "heartbeat_ms": 60000,
    "pour_update_ms": 1000,
    "queue_capacity": 16
  },
  "meters": [
    { "meter_number": 0, "total_ticks": 918234, "ml_per_tick": 0.185 },
    { "meter_number": 1, "total_ticks": 40112, "ml_per_tick": 0.185 }
  ],
  "relays": [
    { "relay_number": 0 },
    { "relay_number": 1 }
  ]
}
```

| Field | Type | Req | Description |
|---|---|---|---|
| `state` | string | yes | `boot` for the first status after power-on, else `heartbeat`. |
| `fw_version` | string | yes | Firmware version. |
| `uptime_ms` | integer | yes | Uptime at event creation. |
| `wifi_rssi_dbm` | integer | no | Signal strength. |
| `events_dropped` | integer | yes | Lifetime count of events evicted from the queue before delivery. A non-zero delta between heartbeats means data was lost. |
| `config` | object | yes | Operative device settings the server should be able to discover without being able to set them: heartbeat interval, pour-update interval, queue capacity. Extensible; servers MUST ignore unknown keys. |
| `meters` | array | no | Every meter the device has, with lifetime tick totals and current calibration (`ml_per_tick` always present). Exhaustive when present: a meter absent from the list does not exist on the device. Also lets a server detect missed pours by gap analysis. |
| `relays` | array | no | Every relay (valve output) the device has. Exhaustive when present, same rule as `meters`. Entries are objects for extensibility; servers MUST ignore unknown keys. |

A server that auto-provisions from these inventories SHOULD be
conservative about retirement: dropping a record it created is safe, but
a port an operator has configured (e.g. bound to a tap) deserves a
warning rather than silent deletion — a transient misreport must not
sever operator configuration.

### 5.6 `command_result`

Acknowledges a server command (§7), giving the command channel the same
at-least-once/idempotent semantics as the event channel.

```json
{ "command": "cmd_8f21", "result": "ok" }
```

| Field | Type | Req | Description |
|---|---|---|---|
| `command` | string | yes | The `id` of the command being acknowledged. |
| `result` | string | yes | `ok`, `error`, or `unsupported`. |
| `message` | string | no | Human-readable detail on `error`/`unsupported`. |

### 5.7 `grant_end`

Reports that an authorization grant (§7.1) ended, and why. Emitted once per
ending — including partial endings, where only some of a grant's meters are
released — so the server gets the complete grant lifecycle from this one
event type instead of inferring it from timers of its own.

```json
{
  "meter_numbers": [0],
  "reason": "max_volume",
  "auth_device": "core.rfid",
  "auth_token": "0089f2c4",
  "grant_id": "g_5501",
  "volume_ml": 2004.9,
  "duration_ms": 84200
}
```

| Field | Type | Req | Description |
|---|---|---|---|
| `meter_numbers` | array of integer | yes | The meters released by this ending. |
| `reason` | string | yes | Why the grant ended; see below. |
| `auth_device` / `auth_token` | string | no | Echo of the presentment that created the grant, as on `pour` (§5.1). |
| `grant_id` | string | yes | The server-assigned id of the grant (§7.1). |
| `volume_ml` | number | yes | Total volume poured under the grant, across all its meters — a snapshot at this ending, see below. |
| `duration_ms` | integer | yes | Grant age at this ending. |

| `reason` | Meaning |
|---|---|
| `max_volume` | Cumulative poured volume reached `max_volume_ml`. |
| `max_duration` | Grant lifetime reached `max_duration_ms` — or the device's own `max_grant_duration` clamp (§7.1). |
| `max_idle` | No flow on any granted meter for `max_idle_ms`. |
| `detach` | The grant's token detached (presence readers). |
| `command` | A server `deauthorize` (§7.3). |
| `replaced` | An `authorize` — a new grant, or an update to this one — took the listed meters out of this grant's scope (§7.1). |

`volume_ml` and `duration_ms` are **snapshots of the whole grant, not
deltas**: a partial ending reports the grant's running totals at that
moment, and the same volume appears again — grown — in the grant's later
endings. Servers MUST NOT sum `grant_end` volumes; the `pour` events are
the volume record, and these totals are for cross-checking and display.

A limit ending an in-flight pour ends the pour first, so the final `pour`
event precedes the `grant_end` in the queue. Reason `command` is redundant
with the `deauthorize`'s own `command_result` acknowledgment, deliberately:
a server can track grant lifecycles from `grant_end` alone. Like any event,
`grant_end` queues and delivers at-least-once (§9) — a grant that ends
during an outage is reported when connectivity returns.

## 6. Time model

The device may not have wall-clock time — at boot, before NTP, or on a
network with no time source. The protocol therefore never depends on the
device's clock:

- **`age_ms` is authoritative.** The receiving server computes
  `event_time = server_now - age_ms`. Because `age_ms` is recomputed each
  time the batch is serialized, this stays correct for queued events
  delivered hours late and on devices that never sync.
- **`time` is informational.** Present only when the device clock was synced
  at event creation. Servers MAY log it, SHOULD prefer `age_ms`, and MUST NOT
  reject events over disagreement between the two.

Transit latency adds error on the order of the HTTP round trip; for pours and
temperatures this is noise.

## 7. Response and commands

The response to every 2xx exchange, authenticated or not:

```json
{
  "commands": [
    { "id": "cmd_8f21", "type": "authorize", "data": { ... } }
  ]
}
```

| Field | Type | Req | Description |
|---|---|---|---|
| `commands` | array | no | Server→device instructions, oldest first. Absent means none — equivalent to `[]`. |
| `commands[].id` | string | yes | Server-assigned, opaque. Devices MUST deduplicate on it: a server re-sends a command until it sees a `command_result`, so the same command may arrive more than once. A duplicate is not re-applied but SHOULD be acknowledged again — the earlier `command_result` may have been lost before delivery. |
| `commands[].type` | string | yes | Command type. Devices MUST acknowledge unknown types with `result: "unsupported"`. |
| `commands[].data` | object | yes | Type-specific payload. |

This channel is poll-based by design: the device already initiates a request
on every pour, token presentment, and heartbeat, so no listener, NAT
traversal, or second credential is needed. Worst-case command latency equals
the heartbeat interval (1 min default); token-triggered commands arrive in
the same round trip as the token event (see companion doc). A future
transport (WebSocket/MQTT) can push the same command objects unchanged.

The complete command catalog follows. How these commands compose with token
presentment into an authorization flow — including offline behavior — is
specified in
[Authenticated Pouring](authenticated-pouring.md).

### 7.1 `authorize`

Creates — or updates — a grant: the device energizes the grant's relays and
tags pours on the grant's meters with it. One command carries exactly one
grant; a server issuing several grants at once — different taps, different
policy — sends several `authorize` commands in the same response. Typically
sent in the same response as a decision-requesting `token` event (see
companion doc), but valid in any response.

```json
{
  "id": "cmd_8f21",
  "type": "authorize",
  "data": {
    "grant_id": "g_5501",
    "meter_numbers": [0],
    "relay_numbers": [1],
    "max_volume_ml": 2000,
    "max_duration_ms": 120000,
    "max_idle_ms": 30000,
    "auth_device": "core.rfid",
    "token": "0089f2c4"
  }
}
```

| Field | Type | Req | Description |
|---|---|---|---|
| `grant_id` | string | yes | Server-assigned grant identifier: opaque to the device, at most 64 chars. Pours and `grant_end` events echo it (§5.1, §5.7); `deauthorize` revokes by it (§7.3). Naming a live grant's id updates that grant in place (below). |
| `meter_numbers` | array of integer | yes | Meters this grant covers: pours on them are tagged with the grant, and their flow feeds the volume and idle limits. **The server decides the set** — this is how one token opens one tap, several, or all. |
| `relay_numbers` | array of integer | no | Relays to energize (typically driving solenoid valves) for the life of the grant. Absent or empty → attribution-only: the meters still meter, no valve is driven. |
| `max_volume_ml` | number | no | Most the grant may pour, summed across its meters. `0` or absent → unlimited. |
| `max_duration_ms` | integer | no | Hard cap on grant lifetime, from grant creation — reaching it ends the grant even mid-pour. `0` or absent → unbounded by the server; the device clamp below still applies. |
| `max_idle_ms` | integer | no | Longest stretch with no flow on any granted meter. Flow resets it, so this — not `max_duration_ms` — is what keeps a slow glass alive. `0` or absent → no idle limit. |
| `auth_device` / `token` | string | no | Echo of the presentment that triggered this grant. The device records them onto resulting `pour` events and uses them to release the grant on the matching detach. |

Device semantics:

- **The meter↔relay association stays on the server.** The device applies
  the two sets verbatim — energize `relay_numbers`, cover `meter_numbers` —
  and holds no mapping between them; nothing in grant behavior depends on
  which relay serves which meter.
- One active grant **per meter**. A new grant covering an already-covered
  meter takes that meter over — the person at the tap is whoever presented
  most recently. The takeover is reported as `grant_end` with reason
  `replaced` (§5.7).
- **Updates.** An `authorize` (under a new command id) naming a live
  grant's `grant_id` updates it in place: the sets and limits are replaced,
  while poured volume and grant age carry over. This is how a server tops
  up a volume budget or extends a session without ending the grant. Meters
  leaving the scope are reported as `grant_end` with reason `replaced`. An
  update cannot extend a grant past the device clamp (below); for more
  time, issue a new grant.
- A relay is energized while **any** active grant names it, and released
  when the last such grant ends.
- Pours on a granted meter carry the grant's `auth_device`/`auth_token`
  echo and its `grant_id` (§5.1). A grant ending mid-pour ends the pour
  first, so a pour is always tagged with the grant that actually poured
  it. A grant *arriving* mid-pour adopts the in-flight pour, and a grant
  *replacing* another mid-pour splits it — the full pour×grant corner-case
  catalog is in the companion doc (§8).
- **Limits end grants locally.** When any limit is reached the device
  deauthorizes the grant itself — relays released, in-flight pour ended —
  and reports a `grant_end` event (§5.7) naming which limit tripped.
  Volume enforcement is best-effort at the margin: the valve closes the
  moment the limit trips, but beer already in flight still registers, so
  the final pour may slightly overshoot `max_volume_ml`.
- A grant naming a meter or relay the device does not have is acknowledged
  `error` and not applied, in whole.
- **Safety backstop:** the device clamps every grant's total lifetime —
  from creation, updates included — to its own `max_grant_duration`
  (default **5 minutes**), whatever `max_duration_ms` says — including
  "unlimited". A server asking for more
  gets the clamp, silently; the command is still acknowledged `ok`. A valve
  is a thing that pours beer on the floor when software misbehaves, so the
  final bound on "how long can it stay open" belongs to the device.
- Applying the same command id twice is a full no-op — limits, counters,
  and timers are not reset (idempotent, since the server re-sends until
  acked).

### 7.2 `deny`

The explicit refusal of a token presentment. The device signals the user
(refusal tone, LED) and acknowledges with `command_result: ok`. No state
changes: existing grants on other meters are untouched.

```json
{
  "id": "cmd_8f23",
  "type": "deny",
  "data": {
    "auth_device": "core.rfid",
    "token": "0089f2c4",
    "reason": "Token not assigned to a user"
  }
}
```

| Field | Type | Req | Description |
|---|---|---|---|
| `auth_device` / `token` | string | no | Echo of the refused presentment, so a device with several readers signals at the right one. |
| `reason` | string | no | Human-readable explanation. Devices with a display MAY show it; all devices MAY log it. |

### 7.3 `deauthorize`

Revokes grants by id: releases their relays, ends any in-flight pour on
their meters (still tagged with the grant that poured it), clears them.
This is the server-initiated cutoff — an admin button, a policy engine, an
emergency stop. Detach and the grant's own limits do the same thing
device-side without a command. Each grant ended this way is also reported
as `grant_end` with reason `command` (§5.7).

```json
{
  "id": "cmd_8f22",
  "type": "deauthorize",
  "data": { "grant_ids": ["g_5501"] }
}
```

| Field | Type | Req | Description |
|---|---|---|---|
| `grant_ids` | array of string | no | Grants to revoke. **Absent means every active grant** — the emergency stop. |

An id matching no active grant is ignored, and the command still
acknowledges `ok`: the grant may simply have ended on its own before the
command arrived, and the `grant_end` stream already tells the server how.

### 7.4 Reserved types

`set_config`, `set_relay`, and `identify` are reserved for a later
revision; until specified, devices answer them with `unsupported`.

## 8. Pairing

Provisions the bearer token so a user never has to transport a credential.
The flow is: an unprovisioned device announces itself; it appears on the
server dashboard **by name**; a human clicks allow or deny.

An unprovisioned device sends ordinary batches (at minimum its `status`
events — pours queue as usual and deliver after pairing) with **no
`Authorization` header**. A server that does not require authentication
simply accepts them, and pairing never begins (§2). A server that requires
authentication responds `401` with a pairing body:

```json
{ "pairing": { "state": "pending" } }
```

| `pairing.state` | Server meaning | Device behavior |
|---|---|---|
| `pending` | Device is on the dashboard awaiting a decision. | Keep events queued. Poll every 5 s for the first minute, then at the heartbeat interval. |
| `allowed` | A human approved this device. `pairing.token` holds the newly provisioned bearer token. | Store the token in flash, retry immediately with `Authorization` set. Queued events deliver. |
| `denied` | A human refused this device. | Stop polling until reboot. |

```json
{ "pairing": { "state": "allowed", "token": "kbe_9c8ef2a1..." } }
```

Rules:

- The token is delivered exactly once, in the `allowed` response. A server
  MUST treat the device's first authenticated request as confirmation and
  MUST NOT return the token again; a device that loses it re-pairs.
- **Any** 401 on an authenticated request — revoked or rotated token — sends
  the device back into this flow. Key rotation is therefore "revoke, then
  re-allow from the dashboard," with no device-side ceremony.
- Device identity is self-asserted (TOFU): the human clicking *allow* against
  the expected device name is the trust decision. TLS protects the token in
  transit. Servers SHOULD show first-seen time and source IP on the pending
  entry to make that decision an informed one.
- A `denied` device stays visible server-side so the decision can be
  reversed; on its next boot it will ask again.

## 9. Delivery semantics

- **At-least-once** for all types except `pour_update` (§5.2). The device
  retries batches on 5xx/network failure with exponential backoff (base
  30 s, cap 5 min). A new pour or token event resets backoff and triggers an
  immediate attempt.
- **Idempotent processing.** Servers MUST deduplicate on
  `(device, boot_id, id)`. A retention window of 7 days is sufficient; the
  device never re-sends anything older than its queue.
- **Bounded queue, oldest-first eviction.** The queue is fixed-size RAM.
  When full, the oldest event is evicted and `events_dropped` increments —
  during a long outage the most recent pours are the ones worth keeping.
  Events do not survive reboot; `boot_id` makes that harmless for dedup.
- **Ordering.** Events within a batch are oldest-first. `id` orders events
  within a boot. Servers should not assume cross-boot ordering.

## 10. Compatibility rules

- Servers MUST ignore unknown fields anywhere in the request.
- Servers MUST accept (2xx) and ignore unknown event `type`s.
- Devices MUST ignore unknown fields in the response, and MUST answer
  unknown command types with `command_result: unsupported`.
- Additive changes (new optional fields, new event types, new command types)
  do not bump `v`. Breaking changes bump `v`, and a server MAY reject
  versions it does not speak with a non-401 4xx.

## 11. Full example

Device pours twice during a server outage, then connectivity returns; one
batch delivers both pours and a heartbeat:

```
POST /kegboard-event HTTP/1.1
Authorization: Bearer kbe_9c8ef2a1...
Content-Type: application/json

{
  "v": 1,
  "device": "kegboard-a1b2c3",
  "boot_id": "9f3a2c1b",
  "sent_uptime_ms": 7523000,
  "events": [
    {
      "id": 17,
      "type": "pour",
      "age_ms": 912000,
      "data": {
        "meter_number": 0,
        "pour_id": "9b0e6a11-2f4c-49d3-8f6a-c1d2e3f40517",
        "volume_ml": 473.1,
        "duration_ms": 9800,
        "auth_device": "core.rfid",
        "auth_token": "0089f2c4",
        "grant_id": "g_5488",
        "ticks": 2557,
        "ml_per_tick": 0.185
      }
    },
    {
      "id": 18,
      "type": "pour",
      "age_ms": 402000,
      "data": { "meter_number": 1, "pour_id": "0d4f9b82-6e3a-4c15-a7b8-2c9d0e1f6a3b", "volume_ml": 355.0, "duration_ms": 7100 }
    },
    {
      "id": 19,
      "type": "status",
      "age_ms": 0,
      "time": "2026-08-03T18:02:11Z",
      "data": {
        "state": "heartbeat",
        "fw_version": "4.0.0",
        "uptime_ms": 7523000,
        "events_dropped": 0,
        "config": { "heartbeat_ms": 60000, "pour_update_ms": 1000, "queue_capacity": 16 },
        "meters": [
          { "meter_number": 0, "total_ticks": 920791, "ml_per_tick": 0.185 },
          { "meter_number": 1, "total_ticks": 42031, "ml_per_tick": 0.185 }
        ],
        "relays": [ { "relay_number": 0 }, { "relay_number": 1 } ]
      }
    }
  ]
}
```

```
HTTP/1.1 200 OK
Content-Type: application/json

{ "commands": [] }
```

The server records pour 17 as having happened 912 s ago and pour 18 as 402 s
ago, regardless of what the device's clock believed.

## Appendix A. Request JSON Schema

Normative, to ship in-repo as `schemas/kegboard-event.schema.json`.

```json
{
  "$schema": "https://json-schema.org/draft/2020-12/schema",
  "$id": "https://kegbot.org/schemas/kegboard-event/1",
  "title": "Kegboard event batch",
  "type": "object",
  "required": [
    "v",
    "device",
    "boot_id",
    "sent_uptime_ms",
    "events"
  ],
  "properties": {
    "v": {
      "const": 1
    },
    "device": {
      "type": "string",
      "minLength": 1,
      "maxLength": 64
    },
    "boot_id": {
      "type": "string",
      "minLength": 1,
      "maxLength": 32
    },
    "sent_uptime_ms": {
      "type": "integer",
      "minimum": 0
    },
    "events": {
      "type": "array",
      "minItems": 1,
      "maxItems": 16,
      "items": {
        "$ref": "#/$defs/event"
      }
    }
  },
  "$defs": {
    "event": {
      "type": "object",
      "required": [
        "id",
        "type",
        "age_ms",
        "data"
      ],
      "properties": {
        "id": {
          "type": "integer",
          "minimum": 1
        },
        "type": {
          "type": "string"
        },
        "age_ms": {
          "type": "integer",
          "minimum": 0
        },
        "time": {
          "type": "string",
          "format": "date-time"
        },
        "data": {
          "type": "object"
        }
      },
      "allOf": [
        {
          "if": {
            "properties": {
              "type": {
                "const": "pour"
              }
            }
          },
          "then": {
            "properties": {
              "data": {
                "$ref": "#/$defs/pour"
              }
            }
          }
        },
        {
          "if": {
            "properties": {
              "type": {
                "const": "pour_update"
              }
            }
          },
          "then": {
            "properties": {
              "data": {
                "$ref": "#/$defs/pour_update"
              }
            }
          }
        },
        {
          "if": {
            "properties": {
              "type": {
                "const": "temperature"
              }
            }
          },
          "then": {
            "properties": {
              "data": {
                "$ref": "#/$defs/temperature"
              }
            }
          }
        },
        {
          "if": {
            "properties": {
              "type": {
                "const": "token"
              }
            }
          },
          "then": {
            "properties": {
              "data": {
                "$ref": "#/$defs/token"
              }
            }
          }
        },
        {
          "if": {
            "properties": {
              "type": {
                "const": "status"
              }
            }
          },
          "then": {
            "properties": {
              "data": {
                "$ref": "#/$defs/status"
              }
            }
          }
        },
        {
          "if": {
            "properties": {
              "type": {
                "const": "command_result"
              }
            }
          },
          "then": {
            "properties": {
              "data": {
                "$ref": "#/$defs/command_result"
              }
            }
          }
        },
        {
          "if": {
            "properties": {
              "type": {
                "const": "grant_end"
              }
            }
          },
          "then": {
            "properties": {
              "data": {
                "$ref": "#/$defs/grant_end"
              }
            }
          }
        }
      ]
    },
    "pour": {
      "type": "object",
      "required": [
        "meter_number",
        "pour_id",
        "volume_ml",
        "duration_ms"
      ],
      "properties": {
        "meter_number": {
          "type": "integer",
          "minimum": 0
        },
        "pour_id": {
          "type": "string",
          "minLength": 1,
          "maxLength": 64
        },
        "volume_ml": {
          "type": "number",
          "exclusiveMinimum": 0
        },
        "duration_ms": {
          "type": "integer",
          "minimum": 0
        },
        "auth_device": {
          "type": "string"
        },
        "auth_token": {
          "type": "string"
        },
        "grant_id": {
          "type": "string",
          "minLength": 1,
          "maxLength": 64
        },
        "ticks": {
          "type": "integer",
          "minimum": 0
        },
        "ml_per_tick": {
          "type": "number",
          "exclusiveMinimum": 0
        },
        "tick_series": {
          "type": "string",
          "pattern": "^\\d+:\\d+( \\d+:\\d+)*$"
        }
      }
    },
    "pour_update": {
      "type": "object",
      "required": [
        "meter_number",
        "pour_id",
        "volume_ml",
        "duration_ms"
      ],
      "properties": {
        "meter_number": {
          "type": "integer",
          "minimum": 0
        },
        "pour_id": {
          "type": "string",
          "minLength": 1,
          "maxLength": 64
        },
        "volume_ml": {
          "type": "number",
          "minimum": 0
        },
        "duration_ms": {
          "type": "integer",
          "minimum": 0
        }
      }
    },
    "temperature": {
      "type": "object",
      "required": [
        "sensor",
        "temp_c"
      ],
      "properties": {
        "sensor": {
          "type": "string",
          "minLength": 1
        },
        "temp_c": {
          "type": "number"
        }
      }
    },
    "token": {
      "type": "object",
      "required": [
        "auth_device",
        "token",
        "action"
      ],
      "properties": {
        "auth_device": {
          "type": "string",
          "minLength": 1
        },
        "token": {
          "type": "string",
          "minLength": 1
        },
        "action": {
          "enum": [
            "attached",
            "detached"
          ]
        }
      }
    },
    "status": {
      "type": "object",
      "required": [
        "state",
        "fw_version",
        "uptime_ms",
        "events_dropped",
        "config"
      ],
      "properties": {
        "state": {
          "enum": [
            "boot",
            "heartbeat"
          ]
        },
        "fw_version": {
          "type": "string"
        },
        "uptime_ms": {
          "type": "integer",
          "minimum": 0
        },
        "wifi_rssi_dbm": {
          "type": "integer"
        },
        "events_dropped": {
          "type": "integer",
          "minimum": 0
        },
        "config": {
          "type": "object",
          "required": [
            "heartbeat_ms",
            "pour_update_ms",
            "queue_capacity"
          ],
          "properties": {
            "heartbeat_ms": {
              "type": "integer",
              "minimum": 1000
            },
            "pour_update_ms": {
              "type": "integer",
              "minimum": 0
            },
            "queue_capacity": {
              "type": "integer",
              "minimum": 1
            }
          }
        },
        "meters": {
          "type": "array",
          "items": {
            "type": "object",
            "required": [
              "meter_number",
              "total_ticks",
              "ml_per_tick"
            ],
            "properties": {
              "meter_number": {
                "type": "integer",
                "minimum": 0
              },
              "total_ticks": {
                "type": "integer",
                "minimum": 0
              },
              "ml_per_tick": {
                "type": "number",
                "exclusiveMinimum": 0
              }
            }
          }
        },
        "relays": {
          "type": "array",
          "items": {
            "type": "object",
            "required": [
              "relay_number"
            ],
            "properties": {
              "relay_number": {
                "type": "integer",
                "minimum": 0
              }
            }
          }
        }
      }
    },
    "command_result": {
      "type": "object",
      "required": [
        "command",
        "result"
      ],
      "properties": {
        "command": {
          "type": "string",
          "minLength": 1
        },
        "result": {
          "enum": [
            "ok",
            "error",
            "unsupported"
          ]
        },
        "message": {
          "type": "string"
        }
      }
    },
    "grant_end": {
      "type": "object",
      "required": [
        "meter_numbers",
        "reason",
        "grant_id",
        "volume_ml",
        "duration_ms"
      ],
      "properties": {
        "meter_numbers": {
          "type": "array",
          "minItems": 1,
          "items": {
            "type": "integer",
            "minimum": 0
          }
        },
        "reason": {
          "enum": [
            "max_volume",
            "max_duration",
            "max_idle",
            "detach",
            "command",
            "replaced"
          ]
        },
        "auth_device": {
          "type": "string"
        },
        "auth_token": {
          "type": "string"
        },
        "grant_id": {
          "type": "string",
          "minLength": 1,
          "maxLength": 64
        },
        "volume_ml": {
          "type": "number",
          "minimum": 0
        },
        "duration_ms": {
          "type": "integer",
          "minimum": 0
        }
      }
    }
  }
}
```

## Appendix B. Response JSON Schema

Normative, to ship in-repo as `schemas/kegboard-event-response.schema.json`.
Covers both the authenticated (200) and pairing (401) responses.

```json
{
  "$schema": "https://json-schema.org/draft/2020-12/schema",
  "$id": "https://kegbot.org/schemas/kegboard-event-response/1",
  "title": "Kegboard event response",
  "type": "object",
  "properties": {
    "commands": {
      "type": "array",
      "items": {
        "type": "object",
        "required": ["id", "type", "data"],
        "properties": {
          "id": { "type": "string", "minLength": 1 },
          "type": { "type": "string" },
          "data": { "type": "object" }
        },
        "allOf": [
          {
            "if": { "properties": { "type": { "const": "authorize" } } },
            "then": { "properties": { "data": { "$ref": "#/$defs/authorize" } } }
          },
          {
            "if": { "properties": { "type": { "const": "deny" } } },
            "then": { "properties": { "data": { "$ref": "#/$defs/deny" } } }
          },
          {
            "if": { "properties": { "type": { "const": "deauthorize" } } },
            "then": { "properties": { "data": { "$ref": "#/$defs/deauthorize" } } }
          }
        ]
      }
    },
    "pairing": {
      "type": "object",
      "required": ["state"],
      "properties": {
        "state": { "enum": ["pending", "allowed", "denied"] },
        "token": { "type": "string", "minLength": 1 }
      },
      "if": { "properties": { "state": { "const": "allowed" } } },
      "then": { "required": ["state", "token"] }
    }
  },
  "$defs": {
    "authorize": {
      "type": "object",
      "required": ["grant_id", "meter_numbers"],
      "properties": {
        "grant_id": { "type": "string", "minLength": 1, "maxLength": 64 },
        "meter_numbers": {
          "type": "array",
          "minItems": 1,
          "items": { "type": "integer", "minimum": 0 }
        },
        "relay_numbers": {
          "type": "array",
          "items": { "type": "integer", "minimum": 0 }
        },
        "max_volume_ml": { "type": "number", "minimum": 0 },
        "max_duration_ms": { "type": "integer", "minimum": 0 },
        "max_idle_ms": { "type": "integer", "minimum": 0 },
        "auth_device": { "type": "string" },
        "token": { "type": "string" }
      }
    },
    "deny": {
      "type": "object",
      "properties": {
        "auth_device": { "type": "string" },
        "token": { "type": "string" },
        "reason": { "type": "string" }
      }
    },
    "deauthorize": {
      "type": "object",
      "properties": {
        "grant_ids": {
          "type": "array",
          "minItems": 1,
          "items": { "type": "string", "minLength": 1, "maxLength": 64 }
        }
      }
    }
  }
}
```

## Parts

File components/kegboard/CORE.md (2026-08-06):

# Kegboard core

The files listed below are the **framework-agnostic core**: the logic that is
genuinely kegboard-specific rather than ESPHome-specific.

- `pour_session.h` / `.cpp` — pour detection state machine
- `tick_series.h` / `.cpp` — bounded `<offset_ms>:<ticks>` diagnostic series
- `json_writer.h` / `.cpp` — minimal JSON serializer
- `events.h` / `.cpp` — event protocol payloads and batch envelope
- `grant_table.h` / `.cpp` — per-meter authorization grants
- `auth_engine.h` / `.cpp` — grant semantics composed with the device: validation, limits, relays, attribution, endings
- `delivery.h` / `.cpp` — send scheduling: backoff, status handling, pairing cadence, command dedup
- `ring_queue.h` — bounded FIFO for offline event buffering

Core code lives in the global `kbcore` namespace, deliberately *not* in
`esphome::kegboard`. The ESPHome component in this same directory occupies
`esphome::kegboard`, and a global `kegboard` namespace would be shadowed by it
from inside the component — every reference would silently need a leading `::`.
`kbcore` sidesteps that.

## Rules

1. **No framework headers.** Core files must not include anything from
   `esphome/`, Arduino, or ESP-IDF. Only the C++ standard library. CI enforces
   this (`script/check-core-purity.py`).
2. **No I/O, no clocks, no timers.** Time is passed in as arguments. This is
   what lets the whole state machine run under host unit tests.
3. **Every core file has host tests** in `tests/core/`, run with plain `g++`
   on every push. No hardware, no toolchain download.

## Why

Choosing ESPHome buys an enormous amount of infrastructure, but it is a
third-party framework that makes breaking changes to its external-component
API on a regular cadence. Keeping the kegboard-specific logic behind this
boundary means the ESPHome components stay thin adapters: if ESPHome ever
becomes untenable, porting to bare ESP-IDF is an adapter rewrite rather than a
firmware rewrite.

It also has an immediate payoff, which is the real reason to bother: pour
detection, calibration, and the queue-and-retry path are the parts most likely
to have subtle bugs, and this is what makes them testable in milliseconds
without flashing a board.

## Note on layout

These files sit directly in `components/kegboard/` rather than a `core/`
subdirectory because ESPHome only copies source files found at the top level
of an external component — `ComponentManifest.resources` descends into
subdirectories only for manifests constructed with `recursive_sources=True`,
which is reserved for ESPHome's own internal components.

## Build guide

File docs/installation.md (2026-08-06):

# Installation

Kegboard is flashed like any ESPHome project: write a YAML config, build,
flash once over USB, then update over the air. Prebuilt binaries and a
browser-based installer are planned but not yet available.

## Install ESPHome

Any current ESPHome (2025.x or later) works. With [uv](https://docs.astral.sh/uv/):

```console
$ uv tool install esphome
```

or `pip install esphome`. See the
[ESPHome installation guide](https://esphome.io/guides/installing_esphome)
for other options, including the Home Assistant add-on.

## Get a configuration

Start from an example:

```console
$ git clone https://github.com/Kegbot/kegboard.git
$ cd kegboard/examples
$ cp secrets.yaml.example secrets.yaml   # fill in WiFi + reporting URL
```

Pick the example matching your [operating mode](operating-modes.md) —
`kegbot-2tap.yaml`, `home-assistant-2tap.yaml`, or `kegbot-full.yaml` — and
trim it to the hardware you actually have.

Configs outside this repository consume the components directly:

```yaml
external_components:
  - source: github://Kegbot/kegboard@main
```

## Board configuration

Each config includes a board package from `boards/`, which selects the chip
and defines the pin map as substitutions:

```yaml
packages:
  board: !include ../boards/esp32-s3-devkitc-1.yaml
  base: !include ../packages/base.yaml
```

To move a peripheral to a different pin, override the substitution in your
config rather than editing the board file. See
[Hardware & Wiring](hardware.md) for the maps and which pins are safe.

The `base` package provides WiFi (with a fallback `kegboard-setup` access
point and captive portal), OTA, logging, the native API, SNTP time, and the
HTTP client.

## Flash

First flash is over USB:

```console
$ esphome run kegbot-2tap.yaml
```

`esphome run` compiles, prompts for the port, flashes, and tails the log.
Every later `esphome run` offers OTA over WiFi instead — the cable is only
ever needed once.

If the board can't reach your WiFi it raises the `kegboard-setup` access
point; connect to it and enter credentials in the captive portal.

## Pair with the server

Nothing to configure: no API key, no token. On first contact with a server
that requires authentication, the board enters pairing and appears on the
server dashboard under its `serial_number` (default `kegboard-<mac>`).
Approve it there; the board stores its credential in flash and is
provisioned from then on. Revoking the credential server-side sends the
board back into pairing, so key rotation is "revoke, then re-allow" with no
device-side ceremony. Details in [protocol §8](kegboard-event-protocol.md).

Events recorded before approval are queued, not lost — they deliver, with
correct timestamps, once pairing completes.

## Verify

- `esphome logs kegbot-2tap.yaml` and blow through a meter (or short the
  meter pin to ground a few times): tick counts should move and a pour
  should end after `idle_timeout`.
- Check the server dashboard for the device and the pour.
- For calibration, pour a known volume and scale `ml_per_tick`; see
  [`kegboard_meter`](configuration.md#kegboard_meter).

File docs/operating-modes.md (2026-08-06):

# Operating Modes

A Kegboard is useful at three levels of integration. The modes are additive,
not exclusive: a board reporting to a Kegbot Server can stay connected to
Home Assistant, and every board works standalone when the network is down.

## Standalone

No server, nothing else on the network. The board meters pours and runs
local automations (`on_pour_start`, `on_pour_end`). Token readers still fire
their triggers, so a serverless board can gate valves with plain ESPHome
automations if wanted. Watch it work with `esphome logs`.

This is also the right mode for bench work: verify wiring and calibration
before pointing the board at anything.

## Home Assistant mode

Enable ESPHome's native `api:` (the `base` package does) and Home Assistant
discovers the board automatically. Every configured entity — tick totals,
pour volume, flow rate, pouring state, temperatures, relays, auth state —
appears in HA for dashboards and automations. No Kegbot Server involved.

`examples/home-assistant-2tap.yaml` is a complete config for this mode.

## Kegbot Server mode

The flagship. Add `kegboard_reporter` with a `reporting_url` and the board
speaks the [Kegboard Event Protocol](kegboard-event-protocol.md):

- Finished pours are POSTed as events with authoritative `volume_ml`,
  attribution, and a diagnostic tick series.
- Events queue during outages and deliver late with correct timestamps.
- The board pairs itself from the server dashboard — no API key to configure.
- Server commands (authorize, deny, valve control) ride back in HTTP
  responses; with `kegboard_auth`, the server decides every token
  presentment.

The server does not have to be Kegbot Server: the protocol is a single
HTTP endpoint with published schemas, and the minimum viable receiver is one
unauthenticated handler.

`examples/kegbot-2tap.yaml` is the starting point;
`examples/kegbot-full.yaml` adds relays, buzzer, RFID, and iButton auth.

## Choosing

| You have | Use |
|---|---|
| A bench and a meter | Standalone |
| Home Assistant | HA mode (keep it enabled in the other modes too — it is how you watch a pour live) |
| A Kegbot Server, or your own receiver | Kegbot Server mode |

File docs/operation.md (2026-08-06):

# Theory of Operation

The internal design of the firmware. Skippable; read it before hacking on the
components or debugging a deployment.

## Structure

Kegboard-specific logic lives in a framework-agnostic core (`kbcore`
namespace, plain C++, no ESPHome/ESP-IDF headers, time passed in as
arguments) that runs under host unit tests. The ESPHome components are thin
adapters around it. Rationale and rules in
[`components/kegboard/CORE.md`](https://github.com/Kegbot/kegboard/blob/main/components/kegboard/CORE.md).

## Flow sensing and pour detection

Each meter pin counts falling edges in an interrupt handler, with a software
debounce (default 1200 µs, matching the legacy firmware). Open-collector
hall-effect meters emit a fixed volume per pulse, so volume is tick count ×
`ml_per_tick` — an odometer.

On top of the counter runs a pour state machine:

- The first tick after idle **starts a pour** (`on_pour_start`, `pouring`
  goes on).
- Silence for `idle_timeout` **ends it**. Pours shorter than
  `min_pour_ticks` are discarded as drips; pours exceeding
  `max_pour_duration` are cut off as a stuck meter.
- The finished pour carries ticks, `volume_ml`, duration, attribution from
  the meter's grant (if any), and a bounded tick time series
  (`series_resolution` buckets) for diagnostics.

Calibration is applied on the device; the reported `volume_ml` is
authoritative, raw ticks are advisory.

## Reporting

The reporter batches events — pours, live pour updates, temperatures, token
presentments, heartbeats, command results — and POSTs them as JSON to
`reporting_url` per the [event protocol](kegboard-event-protocol.md).

- **Queueing.** Events that can't be delivered wait in a bounded queue and
  retry with exponential backoff (base `retry_interval`, capped at 5 min).
  Each event carries its age, so a batch delivered late lands with correct
  timestamps even on a board whose clock never synced. The queue is bounded
  RAM: when full, the oldest events are evicted first — during a long outage
  the most recent pours are the ones worth keeping — and the `dropped`
  counter advances. Events do not survive reboot.
- **Idempotency.** Delivery is at-least-once; `(device, boot_id, id)` makes
  processing idempotent, so a retry can never create a duplicate drink.
- **Heartbeats** every `heartbeat_interval` give the server a liveness signal
  and bound worst-case command latency, since server commands ride only in
  HTTP responses.
- **Pairing.** A 401 sends the device into pairing: it appears on the server
  dashboard, and on approval receives a bearer token, persisted in flash.
  A later 401 revokes it and restarts pairing.

## Authorization

`kegboard_auth` holds no token database and no meter↔relay map — only the
currently active grants, one per meter, each naming its own meters and
relays from the server. A token presentment is flushed to the server
immediately and the decision (`authorize`/`deny`) returns in the same HTTP
round trip; grants end at their server-set limits — volume poured, total
time, idle time — with total time always clamped to `max_grant_duration`,
on token detach, or on a server `deauthorize`. Every ending is reported
upstream as a `grant_end` event naming the reason. Full semantics in
[Authenticated Pouring](authenticated-pouring.md).

## Relays

A relay left on is usually a valve held open. Each relay in
`packages/relays.yaml` starts a watchdog timer when switched on and switches
itself off after `relay_watchdog_timeout`. The timer runs from the on-edge
and cannot be refreshed while the relay is on; it protects relays driven
manually or from Home Assistant. Grant-driven relays are bounded by the
grant clamp (`max_grant_duration`) instead — **set the watchdog longer than
the clamp** (or `0s`) on relays the server grants, or the watchdog will
close the valve mid-grant.

## Buzzer

When a passive piezo is connected, the board plays melodies transcribed from
the AVR firmware:

| Event | Sound |
|---|---|
| Boot complete | Short musical tune (`play_boot_melody`) |
| Token authorized | Rising three-note chirp (`play_auth_melody`) |
| Ping | Two notes (`play_ping_melody`) |

The scripts are plain `rtttl`; wire them to any trigger you like.

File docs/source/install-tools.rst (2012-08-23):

.. _install-kegboard-library:

Install Support Library
=======================

In addition to the Kegboard firmware, the Kegboard package comes with some
support optional tools (``kegboard-monitor`` and ``kegboard-tester``) as well as
a Python library for writing new programs to talk to Kegboard.  This section
will walk you through installing them.

.. note::
  The support tools are automatically installed as part of Pycore.  If you've
  installed Pycore, you can skip this section.

Set up virtualenv
-----------------

.. note::
  If you've already installed Kegbot Server or Pycore in its own virtualenv, you
  don't need to create a new one just for Kegbot; it's perfectly fine to reuse
  the existing virtualenv.

The ``virtualenv`` tool creates a directory where the Kegboard support programs
and all of their Python dependencies will be stored.  It makes it easier to
install the tools without needing root privileges, and reduces the chance of
Kegboard clashing with your system's Python modules.

The first time you set up Kegboard, you will need to create a new virtualenv
"home" for it.  Any filesystem location is fine.  To create it, give the
directory name as the only argument.  The example below creates the Kegboard
virtualenv directory in your user's home directory::

  $ virtualenv ~/kegboard
  New python executable in /Users/mike/kegboard/bin/python
  Installing setuptools............done.
  Installing pip...............done.

Now that the virtualenv home has been created (at ``~/kegboard/``), there's one
step to remember.  Each time you want to use the virtualenv home (to use the
support tools) you need to activate it for the current shell::

  $ source ~/kegboard/bin/activate
  (kegboard) $

Your shell prompt will be updated with ``(kegboard)`` when the virtualenv is
active.  If you want to step out of the env for some reason, just call
``deactivate``::

  (kegboard) $ deactivate
  $

If you ever want to completely uninstall Kegboard, just delete the entire
``kegboard/`` directory -- there's nothing precious in it, and you can always
recreate it by following these steps again.

.. tip::
  You can install multiple versions of Kegboard simply by creating a new
  virtualenv for each one.

Install Kegboard
----------------

There are two approaches to downloading and installing Kegbot:

* :ref:`From the latest release, using pip <install-kegboard-release>`, the
  recommended way to quickly get going with the latest release.
* :ref:`From Git <install-kegboard-git>`, to grab the latest, bleeding-edge
  development code.  Recommended for advanced users only.

If in doubt, proceed to the next section for the easiest method.  Be sure you
have activated your virtualenv first.

.. _install-kegboard-release:

From Latest Release (Recommended)
^^^^^^^^^^^^^^^^^^^^^^^^^^^^^^^^^

Use the ``pip`` tool to install the latest release of Kegboard, including its
dependencies::

	(kegboard) $ pip install kegbot-kegboard

The command may take a few minutes as it downloads and installs everything.

.. _install-kegboard-git:

From Git (developers)
^^^^^^^^^^^^^^^^^^^^^

If you want to run Kegboard from the latest development version, follow this
section.

.. warning::
  Running from unreleased git sources is not recommended for production systems,
  since code can be very unstable and functionality may change suddenly.
  **Always** back up your valuable data.  As stated in Kegbot's license, we
  provide Kegbot with absolutely no warranty.

#. Check out the Kegboard sources using ``git``::

	(kegboard) $ git clone https://github.com/Kegbot/kegboard.git

#. Step in to the new tree and run the setup command::

	(kegboard) $ cd kegbot/python
	(kegboard) $ ./setup.py develop

The command may take a few minutes as it downloads and installs everything.

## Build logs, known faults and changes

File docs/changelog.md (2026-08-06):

# Changelog

## Current version (in development)

* First esp32/esphome firmware release.
* First release of Kegboard Event Protocol.

## Earlier changelog entries

_For previous changelog entries, see [`changelog.rst@arduino`](https://github.com/Kegbot/kegboard/blob/arduino/docs/source/changelog.rst)._

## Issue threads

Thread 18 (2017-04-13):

'PCMSK1' was not declared in this scope

mikecole20, 2017-04-13:
I'm trying to get this running on an Arduino Micro, but I get an error when trying to Verify.

```
exit status 1
'PCMSK1' was not declared in this scope
```

However, if I set the board to another option (Uno for example), it verifies properly.

## Screenshot
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

patfreeman, 2017-07-14:
I recently updated my Arduino IDE and ran into the same problem. After some trial and error I found a workaround:

Tools -> Board -> Boards Manager
Click Arduino AVR Boards
Select version 1.6.11 or less
Click Install

phil123456, 2023-09-26:
what the ... ???

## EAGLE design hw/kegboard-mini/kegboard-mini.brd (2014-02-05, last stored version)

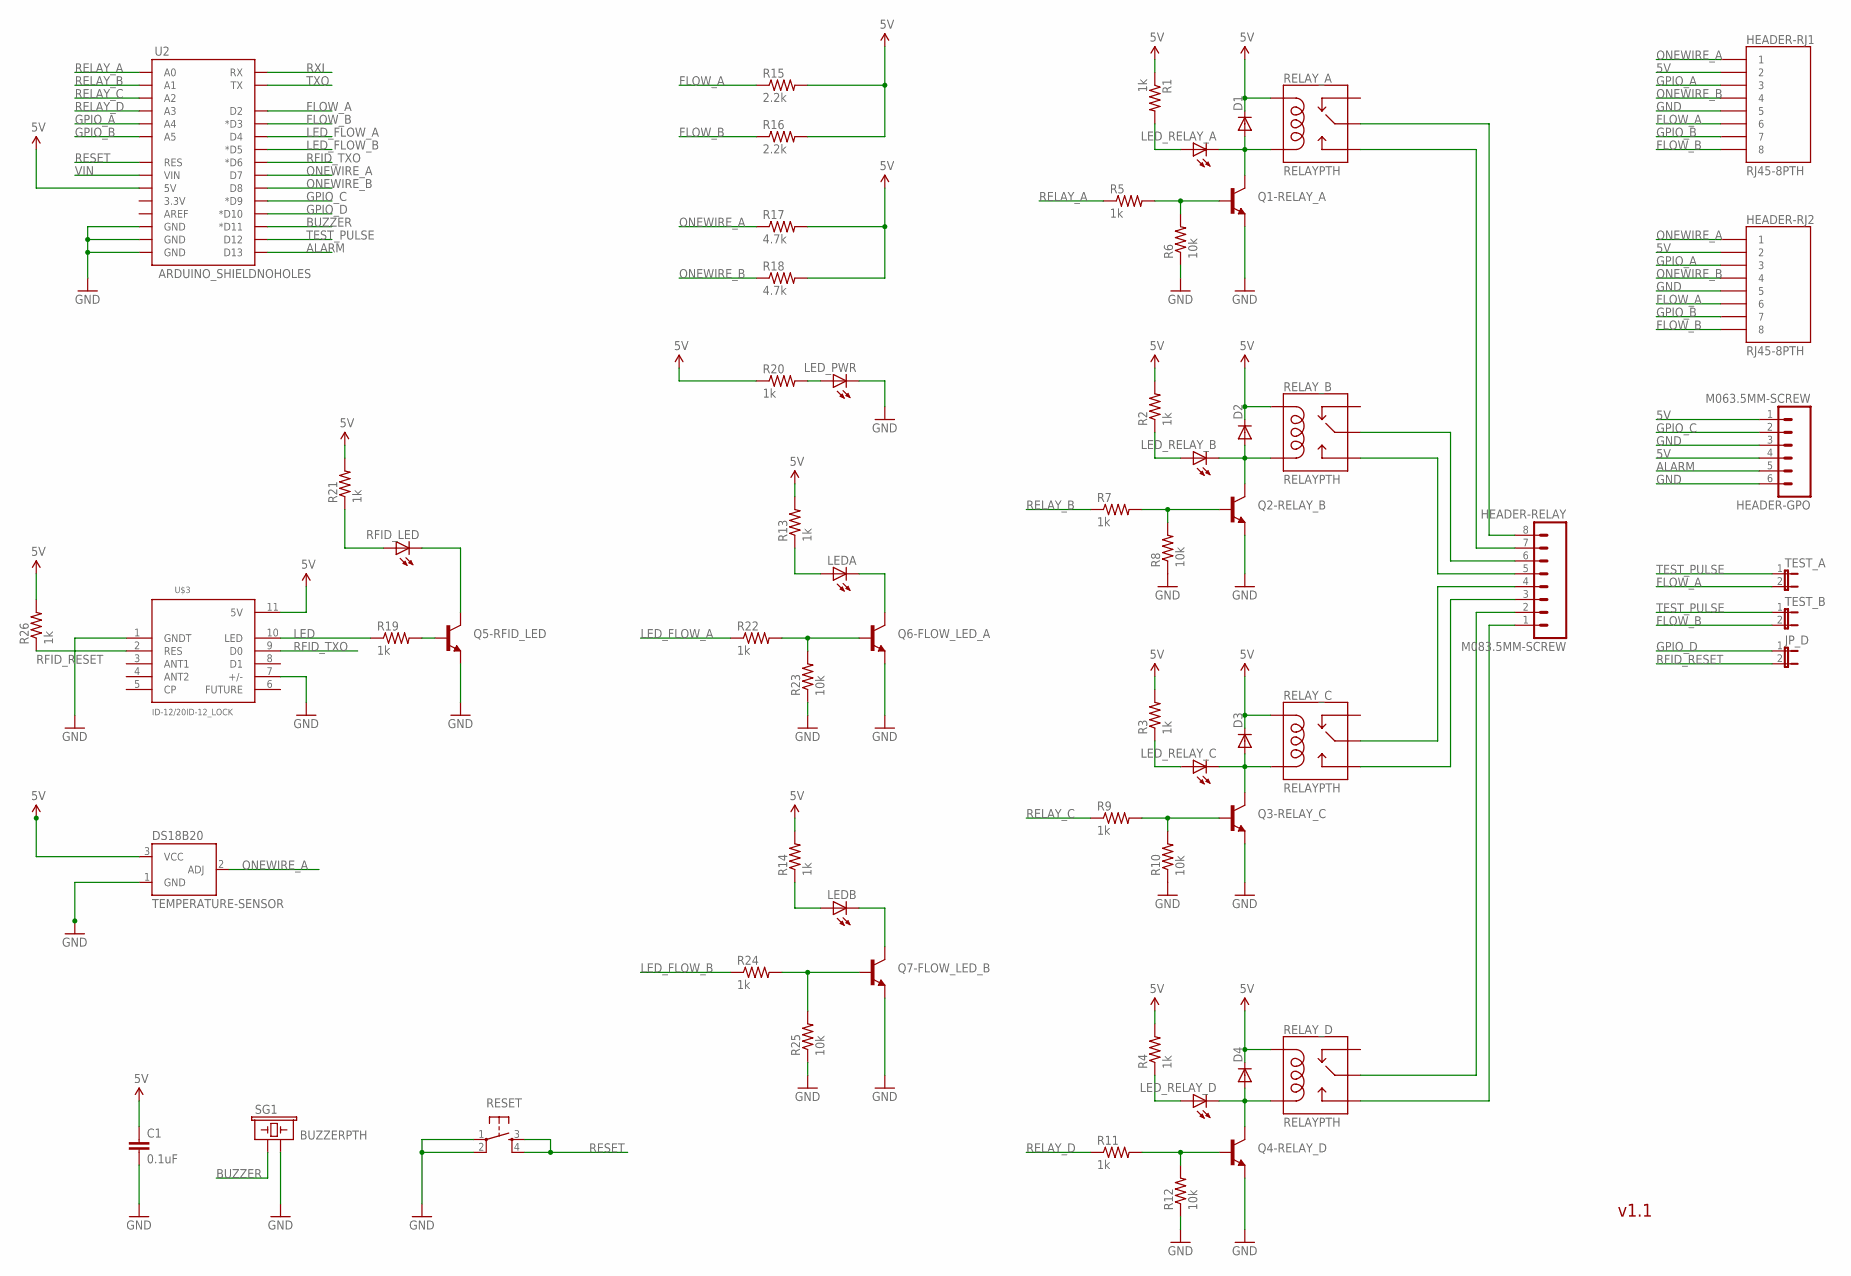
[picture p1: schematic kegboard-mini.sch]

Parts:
C1: 0.1uF; CAP-PTH-SMALL
D1, D2, D3, D4: DIODE1N4148; DIODE-1N4148
DS18B20: TEMPERATURE-SENSOR; TO-92
HEADER-GPO: M063.5MM-SCREW; SCREWTERMINAL-3.5MM-6
HEADER-RELAY: M083.5MM-SCREW; SCREWTERMINAL-3.5MM-8
HEADER-RJ1, HEADER-RJ2: RJ45-8PTH; RJ45-8
JP_D: JUMPER-2PTH; 1X02
LEDA: LED3MM
LEDB: LED3MM
LED_PWR: LED3MM
LED_RELAY_A: LED3MM
LED_RELAY_B: LED3MM
LED_RELAY_C: LED3MM
LED_RELAY_D: LED3MM
Q1-RELAY_A, Q2-RELAY_B, Q3-RELAY_C, Q4-RELAY_D, Q5-RFID_LED, Q6-FLOW_LED_A, Q7-FLOW_LED_B: TRANSISTOR_NPNTO92; TO-92
R1, R2, R3, R4, R5, R7, R9, R11, R13, R14, R19, R20, R21, R22, R24, R26: 1k; AXIAL-0.3
R6, R8, R10, R12, R23, R25: 10k; AXIAL-0.3
R15, R16: 2.2k; AXIAL-0.3
R17, R18: 4.7k; AXIAL-0.3
RELAY_A: RELAYPTH; RELAY-G5Q
RELAY_B: RELAYPTH; RELAY-G5Q
RELAY_C: RELAYPTH; RELAY-G5Q
RELAY_D: RELAYPTH; RELAY-G5Q
RESET: TAC_SWITCHPTH; TACTILE-PTH
RFID_LED: LED3MM
SG1: BUZZERPTH; BUZZER-12MM
TEST_A: JUMPER-2PTH; 1X02
TEST_B: JUMPER-2PTH; 1X02
U2: ARDUINO_SHIELDNOHOLES; DUEMILANOVE_SHIELD_NOHOLES
U$3: ID-12/20ID-12_LOCK; ID-12_LOCK

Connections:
5V: C1.1, D1.C, D2.C, D3.C, D4.C, DS18B20.3 (VCC), HEADER-GPO.1, HEADER-GPO.4, HEADER-RJ1.2, HEADER-RJ2.2, R1.P$1 (1), R2.P$2 (2), R3.P$2 (2), R4.P$2 (2), R13.P$2 (2), R14.P$2 (2), R15.P$2 (2), R16.P$2 (2), R17.P$2 (2), R18.P$2 (2), R20.P$1 (1), R21.P$2 (2), R26.P$2 (2), RELAY_A.5 (COIL1), RELAY_B.5 (COIL1), RELAY_C.5 (COIL1), RELAY_D.5 (COIL1), U2.5V, U$3.11 (5V)
ALARM: HEADER-GPO.5, U2.D13
BUZZER: SG1.+ (1), U2.D11 (*D11)
FLOW_A: HEADER-RJ1.6, HEADER-RJ2.6, R15.P$1 (1), TEST_A.2, U2.D2
FLOW_B: HEADER-RJ1.8, HEADER-RJ2.8, R16.P$1 (1), TEST_B.2, U2.D3 (*D3)
GND: C1.2, DS18B20.1 (GND), HEADER-GPO.3, HEADER-GPO.6, HEADER-RJ1.5, HEADER-RJ2.5, LED_PWR.K (C), Q1-RELAY_A.1 (E), Q2-RELAY_B.1 (E), Q3-RELAY_C.1 (E), Q4-RELAY_D.1 (E), Q5-RFID_LED.1 (E), Q6-FLOW_LED_A.1 (E), Q7-FLOW_LED_B.1 (E), R6.P$1 (1), R8.P$1 (1), R10.P$1 (1), R12.P$1 (1), R23.P$1 (1), R25.P$1 (1), RESET.1, RESET.2, SG1.- (2), U2.GND@0 (GND), U2.GND@1 (GND), U2.GND@2 (GND), U$3.1 (GNDT), U$3.7 (+/-)
GPIO_A: HEADER-RJ1.3, HEADER-RJ2.3, U2.A4
GPIO_B: HEADER-RJ1.7, HEADER-RJ2.7, U2.A5
GPIO_C: HEADER-GPO.2, U2.D9 (*D9)
GPIO_D: JP_D.1, U2.D10 (*D10)
LED: R19.P$1 (1), U$3.10 (LED)
LED_FLOW_A: R22.P$1 (1), U2.D4
LED_FLOW_B: R24.P$1 (1), U2.D5 (*D5)
unnamed: LED_RELAY_A.A, R1.P$2 (2)
unnamed: Q2-RELAY_B.2 (B), R7.P$2 (2), R8.P$2 (2)
unnamed: Q1-RELAY_A.2 (B), R5.P$2 (2), R6.P$2 (2)
unnamed: Q3-RELAY_C.2 (B), R9.P$2 (2), R10.P$2 (2)
unnamed: LED_RELAY_C.A, R3.P$1 (1)
unnamed: Q4-RELAY_D.2 (B), R11.P$2 (2), R12.P$2 (2)
unnamed: LED_RELAY_B.A, R2.P$1 (1)
unnamed: LEDB.K (C), Q7-FLOW_LED_B.3 (C)
unnamed: LEDA.K (C), Q6-FLOW_LED_A.3 (C)
unnamed: D1.A, LED_RELAY_A.K (C), Q1-RELAY_A.3 (C), RELAY_A.1 (COIL2)
unnamed: LED_RELAY_D.A, R4.P$1 (1)
unnamed: D2.A, LED_RELAY_B.K (C), Q2-RELAY_B.3 (C), RELAY_B.1 (COIL2)
unnamed: LED_PWR.A, R20.P$2 (2)
unnamed: D3.A, LED_RELAY_C.K (C), Q3-RELAY_C.3 (C), RELAY_C.1 (COIL2)
unnamed: HEADER-RELAY.8, RELAY_A.2 (MAIN)
unnamed: D4.A, LED_RELAY_D.K (C), Q4-RELAY_D.3 (C), RELAY_D.1 (COIL2)
unnamed: Q5-RFID_LED.2 (B), R19.P$2 (2)
unnamed: R21.P$1 (1), RFID_LED.A
unnamed: Q5-RFID_LED.3 (C), RFID_LED.K (C)
unnamed: HEADER-RELAY.7, RELAY_A.3 (NO)
unnamed: HEADER-RELAY.6, RELAY_B.2 (MAIN)
unnamed: HEADER-RELAY.5, RELAY_B.3 (NO)
unnamed: HEADER-RELAY.4, RELAY_C.2 (MAIN)
unnamed: LEDA.A, R13.P$1 (1)
unnamed: HEADER-RELAY.3, RELAY_C.3 (NO)
unnamed: HEADER-RELAY.2, RELAY_D.2 (MAIN)
unnamed: HEADER-RELAY.1, RELAY_D.3 (NO)
unnamed: LEDB.A, R14.P$1 (1)
unnamed: Q6-FLOW_LED_A.2 (B), R22.P$2 (2), R23.P$2 (2)
unnamed: Q7-FLOW_LED_B.2 (B), R24.P$2 (2), R25.P$2 (2)
ONEWIRE_A: DS18B20.2 (ADJ), HEADER-RJ1.1, HEADER-RJ2.1, R17.P$1 (1), U2.D7
ONEWIRE_B: HEADER-RJ1.4, HEADER-RJ2.4, R18.P$1 (1), U2.D8
RELAY_A: R5.P$1 (1), U2.A0
RELAY_B: R7.P$1 (1), U2.A1
RELAY_C: R9.P$1 (1), U2.A2
RELAY_D: R11.P$1 (1), U2.A3
RESET: RESET.3, RESET.4, U2.RES
RFID_RESET: JP_D.2, R26.P$1 (1), U$3.2 (RES)
RFID_TXO: U2.D6 (*D6), U$3.9 (D0)
RXI: U2.RX
TEST_PULSE: TEST_A.1, TEST_B.1, U2.D12
TXO: U2.TX
VIN: U2.VIN

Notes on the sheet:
v1.1

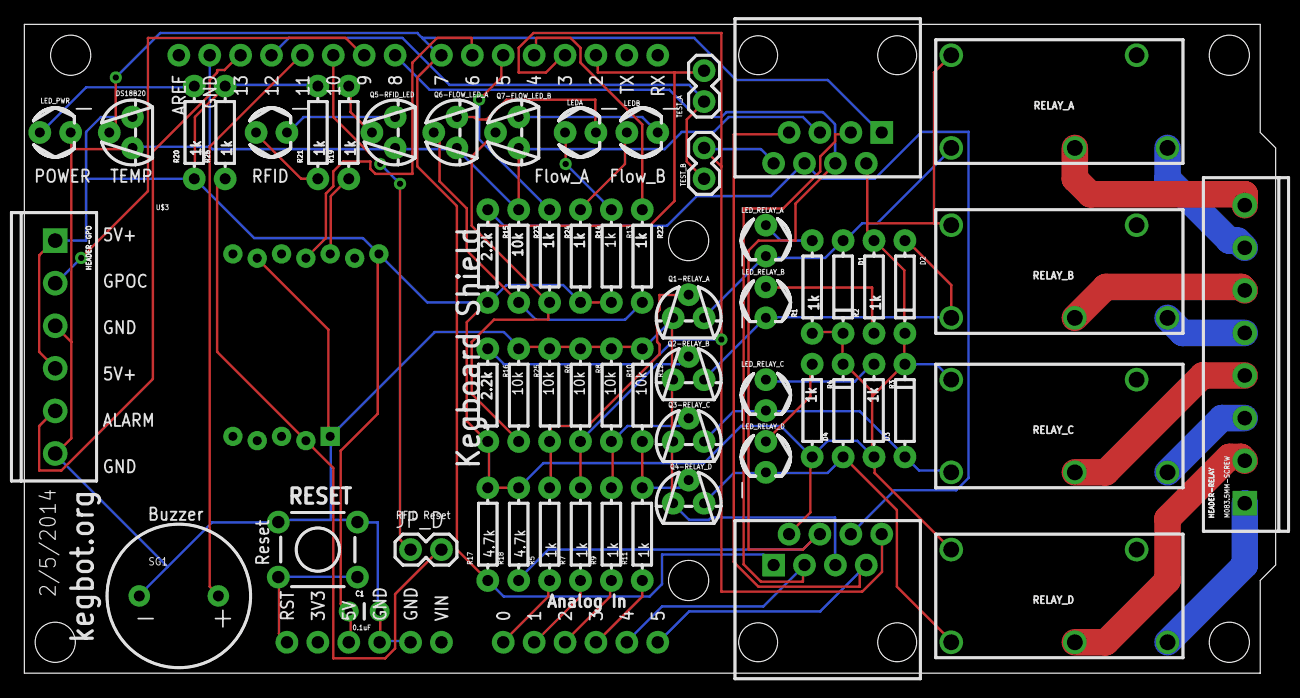
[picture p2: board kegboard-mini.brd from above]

Board: 2 copper layers, 102.9 x 53.3 mm, 68 parts (0 on the bottom side), 53 nets.

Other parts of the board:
JP1, JP2, JP3, JP4, JP5, JP6: STAND-OFF

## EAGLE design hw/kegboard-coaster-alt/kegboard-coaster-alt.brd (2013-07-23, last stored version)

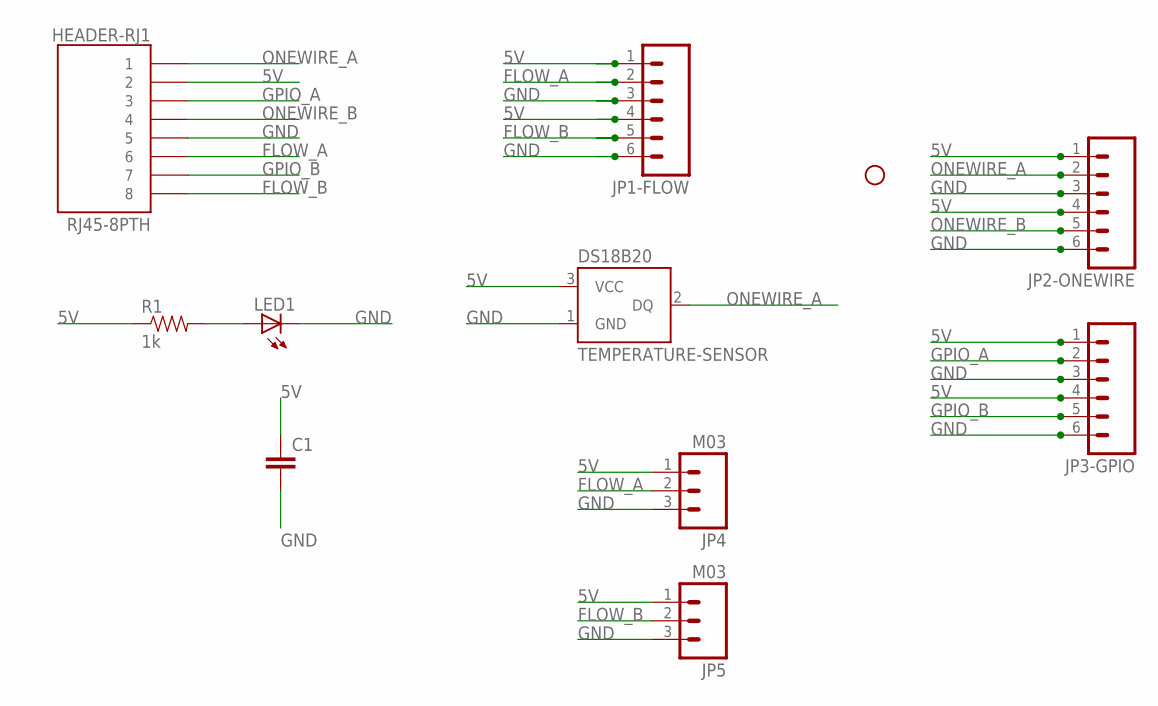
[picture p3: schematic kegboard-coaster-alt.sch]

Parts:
C1: CAPPTH2; CAP-PTH-SMALL2
HEADER-RJ1: RJ45-8PTH; RJ45-8
JP1-FLOW, JP2-ONEWIRE, JP3-GPIO: M063.5MM-6; SCREWTERMINAL-3.5MM-6
JP2: STAND-OFF
JP4, JP5: M03; 53324-0360
LED1: LED3MM
R1: 1k; AXIAL-0.3
U$1: TEMPERATURE-SENSOR; TO-92

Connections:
5V: C1.1, HEADER-RJ1.2, JP1-FLOW.1, JP1-FLOW.4, JP2-ONEWIRE.1, JP2-ONEWIRE.4, JP3-GPIO.1, JP3-GPIO.4, JP4.1, JP5.1, R1.P$1 (1), U$1.3 (VCC)
FLOW_A: HEADER-RJ1.6, JP1-FLOW.2, JP4.2
FLOW_B: HEADER-RJ1.8, JP1-FLOW.5, JP5.2
GND: C1.2, HEADER-RJ1.5, JP1-FLOW.3, JP1-FLOW.6, JP2-ONEWIRE.3, JP2-ONEWIRE.6, JP3-GPIO.3, JP3-GPIO.6, JP4.3, JP5.3, LED1.K (C), U$1.1 (GND)
GPIO_A: HEADER-RJ1.3, JP3-GPIO.2
GPIO_B: HEADER-RJ1.7, JP3-GPIO.5
unnamed: LED1.A, R1.P$2 (2)
ONEWIRE_A: HEADER-RJ1.1, JP2-ONEWIRE.2, U$1.2 (DQ)
ONEWIRE_B: HEADER-RJ1.4, JP2-ONEWIRE.5

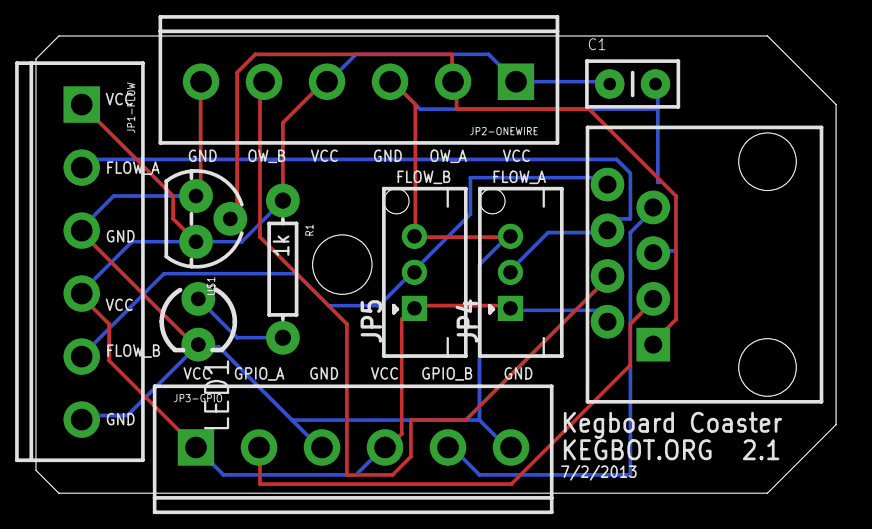
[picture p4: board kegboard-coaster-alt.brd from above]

Board: 2 copper layers, 44.5 x 25.4 mm, 11 parts (0 on the bottom side), 9 nets.

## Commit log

2006-04-03 - cleaned up kegboard.jal - added jpic comptabile pin/register definitions -- I must have inherited a bunch of weird naming conventions from JALss - added a Makefile
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2006-04-03 - update to constantly push status (1x/second in normal case, 5x/second in flow) - added some untested procedures for printing as ascii :)
2006-04-04 - added human-readable output for all fields in the status packet! - changed command names to all be (a) a single ascii char, and (b) intuitive (ie 'F' to enable fridge, 'f' to disable) - TODO: board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
2012-03-31 Many enhancements to kegboard3.
    - adds onewire support
    - created a non-delay()ing wrapper for ds18*20 sensors
    - temperature conversion now supported
    - adds start of TLV eeprom storage. untested, compiles.
    - many todos and cleanups remain
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2012-03-31 Remove dead eeprom code. Reimplement this later. Allocate pin for buzzer.
2012-03-31 Move buzzer to a pin serviced by timer2 instead of timer0.
    Timer0 is used by arduino delay() routines, which were broken.
2012-03-31 Fix temperature conversion.
    Add protocol version.
2012-03-31 Rename kegboard source tree to satisfy the wacky arduino IDE.
    Resolves issue #6.
2012-03-31 Add 1-wire presence detect to kegboard; rework temperature sensing.
    Details:
    - One bus is now dedicated to temperature sensor (and no longer operates in
    onewire 'skip' mode); the other is now used for presence events.
    - A new KBSP message has been added for presence events, and pykeg side has
    been updated to parse this message. (Auth support for kegboard_daemon to be
    added later.)
    - Temperature events now use the full 1wire ID in composing the name of the
    sensor
    Misc other unrelated changes that are tagging along:
    - Slightly increase to the default frequency of the Kegboard main loop
    - Flow KBSP events are now only reported on change
    - The 'Hello' KBSP even is only sent at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
2012-03-31 Bug fix for onewire changes.
    Also adds support for DS18S20 temperature sensor.
2012-03-31 Stateless monitoring of temperature sensors; serialized reading.
    Simplify the monitoring of temperature sensors, which was needlessly
    complicated. We the lose the ability to control multiple sensors in parallel
    (the control is not serialized), and gain ability to monitor a limitless number
    of sensors.
2012-03-31 Initial support for Atmega 1280 (Arduino Mega).
    Adds 4 more flow meter inputs. Untested.
2012-03-31 Fix bug in OneWire::search.
    The condition where a device disappears mid-search was not handled correctly; as
    a result, a button removed mid search could end up being reported indefinitely.
    This could be easily reproduced by repeatedly searching & wiggling the iButton
    device physically on and off the bus.
    Misc whitespace/style cleanups.
2012-03-31 DS1820 bugfix: Do not report '0' for a sensor that disappears mid-read.
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2012-03-31 Move boot melody data to PROGMEM, saving a few dozen bytes.
    Code and data sizes have significantly shrunk thanks to the past few
    optimizations.
    Output of /usr/bin/avr-size -C --mcu=atmega168 build-cli/kegboard-v3.elf
    At revision 602:
    AVR Memory Usage
    ----------------
    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
2012-03-31 Kegboard: Experimental change to cache onewire device presence and report device absence.
    Written without access to AVR: needs to be tested. Also need update to kegboard
    daemon due to changed semantics of presence packet.
2012-03-31 Small optimizations.
    - Compute crc inline while printing a packet.
    - Refactor handling of multi-byte integer values.
2012-03-31 Clean up onewire search to better match appnote flow chart.
    Check CRC before returning results.
2012-03-31 Update to work with arduino-0018.
    Resolves issue #37.
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2012-03-31 First draft of arduino carrier board (Eagle project files.)
    [kegboard.brd, kegboard.sch]
2012-03-31 Update board and schematic.
    [kegboard.brd, kegboard.sch]
2012-03-31 Fix build in arduino GUI.
    Resolves issue #41.
2012-03-31 Update shield design.
    Changes:
    - now sized for / compatible with Arduino MEGA
    - supports up to 6 flow inputs
    - up to 6 RJ45 sockets
    - 4 output relay blocks
    - 4 general purpose output terminal blocks
    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
    [kegboard.brd, kegboard.sch]
2012-03-31 beerdb: Add image table.
    [kegboard.brd, kegboard.sch]
2012-03-31 Split kegboard shield projects into "mega" and "mini" versions.
    The "mini" version is copied from kegboard.{brd,sch} at hg revision 794. The
    existing kegboard.{brd,sch} have been moved to kegboard-mega.{brd,sch}.
    [kegboard-mega.brd, kegboard-mega.sch, kegboard-mini.brd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]
2012-03-31 Update with changes from geoff culp (geoffculp@gmail.com).
    [kegboard-mini.brd, kegboard-mini.sch]
2012-03-31 Change relay configuration & rework layout.
    - Relay outputs now wired for 'pass-through' connection (external load only; VIN
    muxes removed).
    - Relay block moved to top of board, along with external connector. Board
    height shortened.
    - RJ-11 part switched to RJ-45. The two RJ-45s now have identical pinouts,
    which can support an RJ-11 blue-dot connection (to ONEWIRE_B/auth).
    - Added date label to tPlace layer. (Update with actual mfg date.)
    [kegboard-mini.brd, kegboard-mini.sch]
2012-03-31 Board updates; see ChangeLog.
    [kegboard-coaster.brd, kegboard-coaster.sch, kegboard-mini.brd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]
2012-03-31 kegboard-coaster: tweaking things (see changelog)
    [kegboard-coaster.brd, kegboard-coaster.sch]
2012-03-31 coaster: tweaks to layout; autorouted.
    [kegboard-coaster.brd, kegboard-coaster.sch]
2012-03-31 kegboard-coaster: update pin breakouts.
    [kegboard-coaster.brd, kegboard-coaster.sch]
2012-03-31 kegboard-mini: initial routing.
    [kegboard-mini.brd]
2012-03-31 First attempt at routing the relay section.
    [kegboard-mini.brd]
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2012-03-31 kegboard: fix reporting of negative temperatures.
2012-03-31 kegboard: (hopefully final) updates & routing before initial production.
    - Removed XBee components, replaced with ID-20/ID-12 RFID sensor. I decided
    (or rather guessed) that the RFID sensor would be a more popular choice, and
    the XBee can probably be supported with an additional stackable shield.
    Like the XBee, this component is optional.
    - Moved the RJ-45 jacks to the back-left edge, rather than opposing back
    edges. This makes the routing easier to deal with.
    - Reduced the width of the board (to Arduino-standard 2.1") and added mounting
    holes. Hopefully this makes it easier to fit the combined package in an
    Arduino[-mega] enclosure.
    - Removed some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
    [kegboard-mini.brd, kegboard-mini.sch]
2012-03-31 kegboard: update schematic.
    - Remove notch from upper left corner (thanks geoffc).
    - Add drill hole for arduino uno; rearrange and re-route a few components to
    accomodate (thanks geoffc).
    - Rerouted a trace that had been autorouted too close to the relay rails.
    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
    [kegboard-mini.brd, kegboard-mini.sch]
2012-03-31 kegboard: fix build error with arduino-0022 (issue #77).
    (thanks jared)
2012-03-31 kegboard: fix relay on/off support (`set_output` command); bump to v7.
    This should resolve issue #60.
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2012-03-31 kegboard: coaster updates (1/23 version)
    [kegboard-coaster.brd, kegboard-coaster.sch]
2012-03-31 kegboard: various pcb board layout changes, see change log for details.
    [kegboard-coaster.brd, kegboard-coaster.sch, kegboard-mini.brd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]
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2012-03-31 kegboard: fix for arduino compile error.
2012-03-31 Kegboard: Alternate coaster design. Larger pcb board size for screw terminals.
    [kegboard-coaster-alt.brd, kegboard-coaster-alt.sch]
2012-03-31 kegboard: add logo and bump date.
    [kegboard-mini.brd]
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2012-03-31 kegboard: 8/8/2011 revision, with logo
    [kegboard-mini.brd]
2012-03-31 Reorganize as standalone package.
    [kegboard-coaster-alt.brd, kegboard-coaster-alt.sch, kegboard-coaster.brd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]
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2012-07-18 arduino-mk: fix 'make size' target
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2013-04-30 Arduino: replace makefile with http://ed.am/dev/make/arduino-mk
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2013-04-30 firmware: add experimental software debounce.
    Suspected EMI transients have been observed spuriously triggering the
    external interrupt lines on some systems. Likely this is better solved
    in hardware, however this is not as convenient as a software fix.
    When enabled, ISRs first delay by a fixed about (~1.2ms currently) and
    then inspects the active-low interrupting pin. The delay amount
    was selected somewhat empirically (with a non-SF800 sensor) and
    likely requires tuning to account for differences in sensors.
2013-05-04 arduino: fix preprocessor error when debounce disabled
    Closes #6.
2013-05-08 hw: coaster (alt): add headers for molex 53324-0360 connector.
    [kegboard-coaster-alt.brd, kegboard-coaster-alt.sch]
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2013-07-23 Update coaster to v2.1.
    [kegboard-coaster-alt.brd, kegboard-coaster-alt.sch]
2014-01-11 Don't compile buzzer.o when disabled.
    Should be done in the build system, but the Arduino IDE
    is dumb.
2014-01-11 buzzer: Update to use Arduino tone() library.
    Closes #3.
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2014-01-21 Add EEPROM.h to sketch (to satisfy broken Arduino IDE).
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2014-02-05 kegboard-mini: Clean up board labels, no functional changes; bump to v1.0.1.
    [kegboard-mini.brd, kegboard-mini.sch]
2014-02-06 Clean up Arduino firmware build.
    Enables -Werror on first-party code. Removes Magstripe
    due to compile errors and lack of use (will add it
    back if someone cleans it up).
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2026-08-06 core: rewrite for esp32 on esphome
    Pours are now assembled on-device. Kegbot Server's API already accepts a
    finished pour (POST /api/taps/<meter> with ticks/duration/pour_time/now),
    so the board detects the pour, applies calibration, and posts a drink
    directly: no kegbot-pycore, no usb tether, and a server outage costs a
    retry rather than a pour.
    - legacy avr firmware, the python kbsp library, eagle files, and the old
    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
    [kegboard-coaster-alt.brd, kegboard-coaster-alt.sch, kegboard-coaster.brd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]
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2026-08-06 components: add kegbot server reporter
    Posts finished pours and temperature readings to a kegbot server. This
    is what replaces kegbot-pycore.
    Delivery is queue-first: a completed pour is enqueued, never posted
    inline. The meter's loop stays responsive, and a server that is down,
    slow, or unreachable costs a retry rather than a pour.
    - meters register through add_meter() rather than yaml automations, so a
    pour cannot be lost to a forgotten `on_pour_end:` block
    - pours are sent before temperatures, and only one item per loop
    iteration: each send blocks, so draining a backlog at once would stall
    meter polling and lose ticks
    - 4xx responses are discarded rather than retried. a bad key, a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
2026-08-06 build: add board configs, examples, and ci
    - boards for esp32-s3-devkitc-1 (reference), esp32dev, and esp32-c6,
    each with a pin map. meter pins avoid strapping, flash, native-usb,
    and the input-only 34-39 range, which has no internal pull-ups and so
    cannot bias an open-collector meter
    - packages/base.yaml carries wifi with ap fallback, ota, sntp, and the
    http client
    - worked examples for kegbot server and for home assistant alone
    - ci runs core unit tests, pre-commit, config validation, and an
    esp-idf compile matrix; esphome is pinned so a release cannot land on
    a contributor mid-pr
    - a weekly job builds against esphome dev, so their breaking changes
    show up as a scheduled fail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
2026-08-06 packages: add relays, buzzer, and led pins
    M4 is yaml over stock components; no new c++.
    - each relay gets a watchdog: a relay left on is usually a solenoid
    valve held open, and if whatever turned it on stops talking, nobody is
    left to turn it off. scripts use mode: restart, so re-issuing the on
    command restarts the countdown rather than stacking timers, matching
    the legacy set_output behaviour
    - buzzer plays the avr firmware's boot/auth/ping melodies, transcribed
    from tones.h to rtttl
    - boards gain led, rfid rx, and auth-bus pin substitutions
2026-08-06 core: add auth grant state machine
    One grant at a time: the person at the tap is whoever presented the
    most recent token. Covers both reader styles -- a momentary rfid scan
    expires on its own, a held ibutton is revoked on detach.
    - a different token replaces the grant and clears the resolved
    username, so a newcomer cannot inherit the previous holder's tab
    - detach only revokes if the token matches the active grant; a stale
    event from another reader cannot close someone else's tap
    - extend() pushes expiry out, used to keep the valve open under a pour
    that outlasts the grant window
    - expiry math survives the 32-bit millis rollover
    - 46 assertions; 517 total across the core suites
2026-08-06 components: add token auth and ibutton presence
    kegboard_auth turns token events from any reader (rdm6300, wiegand,
    pn532, kegboard_onewire) into a grant: resolves the user against
    /api/auth-tokens, opens the flow toggle, and attributes pours to the
    resolved username. kegboard_onewire adds the arrive/leave events that
    esphome's one_wire bus lacks, which is the entire point of an ibutton
    reader.
    - authorization is decided on-device: the tap works through a server
    outage and the valve opens at local speed. the trade is that a
    server-side revocation stays valid until the next lookup
    - require_known_token defaults false: an unregistered fob pours as
    guest rather than doing nothing. set tr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
2026-08-06 build: add native host smoke compile
    esphome's host platform compiles the components with the system
    compiler in seconds -- a full c++ type-check with no esp toolchain
    download. ci runs it as the first gate ahead of the esp32 matrix.
    - the smoke config deliberately exercises actions invoked from
    automations with arguments, exactly where an override-signature
    mismatch hides from the plain examples
    - meter's isr drain guards InterruptLock with #ifndef USE_HOST; the
    host platform implements no interrupts to mask (and the "isr" never
    runs there, so the unlocked read is equally correct)
    - kegboard_onewire is absent from the smoke config: esphome's own gpio
    one_wire does not link on hos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
2026-08-06 docs: add event protocol and authenticated pouring specs
    Defines the reporting protocol that replaces both the legacy kbsp
    serial protocol and the legacy pykeg http api. One endpoint
    (POST /kegboard-event), json batches with normative json schemas for
    request and response, bearer auth.
    - device is authoritative for volume: volume_ml always present and
    computed from on-device calibration; ticks/ml_per_tick/tick_series
    ride along as diagnostics only
    - at-least-once delivery with idempotent processing: events dedup on
    (device, boot_id, id); a retried batch can never create a duplicate
    drink. pour_id is a separate globally unique opaque string, usable
    as-is server-side (event ids stay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
2026-08-06 components: speak the event protocol
    Replaces the legacy pykeg client stack (kegboard_kegbot, kegbot_request,
    auth_session) with the kegboard event protocol end to end: a reporter
    that batches events to the configured reporting url, per-meter
    server-decided authorization, and pairing.
    kegboard_reporter:
    - reporting_url is a full url, path included, used verbatim
    - queue-first delivery with backoff; pours and token events reset
    backoff for an immediate attempt, heartbeats and command acks wait
    their turn; non-401 4xx drops the batch and counts the loss
    - pairing is the only way a device gets a credential: unauthenticated
    batches until the server allows the device, provisioned token
    p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
2026-08-06 protocol: remove needless optionality
    - pour.pour_id is required; the device always generates one, so the
    "SHOULD, MUST if updates" caveat described an impossible state
    - pour_update.rate_ml_per_min removed: derivable from volume/duration,
    and better from deltas between successive updates
    - response `commands` is optional; absent means none
    - status.meters[].ml_per_tick is required; ml_per_tick: 0 is now a
    config-time error
2026-08-06 protocol: authentication is optional and server-driven
    A device without a token sends no Authorization header, and a server
    that accepts unauthenticated batches never triggers pairing -- the
    minimum receiver needs no auth machinery. Only a 401 introduces auth,
    and later serves as revocation.
    - pairing section reframed to match: it begins when a server 401s
    - fixes healthy_() requiring is_paired(), which silently suppressed
    pour_update events against auth-less servers
2026-08-06 reporter: log sends at debug, bodies at very-verbose
    Success was silent while failures were loud, which made bring-up blind:
    no way to see what the device actually sent.
    - ESP_LOGD per POST: status, event count, byte size
    - ESP_LOGVV: full request and response bodies; compiled out at default
    log levels, so production builds pay nothing
2026-08-06 tools: add kegboard-sim, a tui kegboard for receiver development
    Speaks the full event protocol so the server side can be built without
    hardware: pairing (pending/allowed/denied, token persisted per
    url+device), batching with recomputed age_ms, command dispatch with
    dedup and command_result acks, per-meter grants with pour attribution.
    Validates every outgoing batch against schemas/ so it cannot drift from
    the protocol. Single-file, runs via `uv run` with inline deps.
    Beyond the basics (pours with live updates and slight per-pour
    variance, temperature logging, preset tokens incl. an unknown fob and a
    presence ibutton), it can misbehave on purpose:
    - kill the heartbeat so server liveness de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
2026-08-06 protocol: status self-describes meters and relays
    - meters and the new relays array are exhaustive hardware inventories,
    so a server can allocate and retire port records automatically;
    retirement guidance says warn, don't delete, for operator-configured
    ports
    - self-explanatory field names: meter_number and relay_number in
    objects, meter_numbers for the authorize/deauthorize arrays; the
    reserved set_output command becomes set_relay
    - "relay" replaces "toggle" throughout (matches the hardware docs,
    relay0/relay1 ports, and esphome entities)
    - schema and simulator updated to match
    - drop the DRAFT note
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2026-08-06 protocol: server-issued grants own scope, limits, and lifecycle
    - authorize carries exactly one grant: a server-assigned grant_id,
    meter_numbers/relay_numbers sets (the meter↔relay association stays
    on the backend and travels in each command), and limits —
    max_volume_ml, max_duration_ms, max_idle_ms, 0 meaning unlimited,
    with the device clamp always bounding total lifetime; re-using a
    live grant_id updates the grant in place, counters intact
    - identity leaves the wire: no user field anywhere — pours and grant
    endings carry grant_id plus the token echo, and the server resolves
    the user itself
    - deauthorize revokes by grant_ids; absent means every active grant
    - new grant_e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
2026-08-06 firmware: implement the grant model
    - GrantTable rewritten around grant objects: server ids, meter/relay
    sets, limits with the clamp spanning updates, per-meter takeover,
    and every ending returned with its reason
    - kegboard_auth validates grants against the device inventory (unknown
    meter/relay acks error, not applied), feeds live flow into the
    limits so a volume cap closes the valve mid-pour, ends pours before
    queueing grant_end, adopts in-flight pours at an explicit policy
    point (authenticated-pouring §9), and revokes by grant id —
    malformed grant_ids never read as the emergency stop
    - reporter gains the numbered relay registry (relays option + status
    inventory), grant_e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
2026-08-06 tools: kegboard-sim speaks the grant protocol
    - authorize/deauthorize by grant: sets, limits, update-in-place, and
    inventory validation, mirroring the firmware
    - limits enforced live: volume cutoff mid-pour, idle and duration
    watchers, with the pour event always preceding its grant_end
    - pour lifecycle matches the corner-case catalog: adoption mid-pour,
    splitting on replacement, zero-volume pours discarded as drips
    - duplicate commands re-acked, detach matches the device/token pair,
    grant endings flush promptly, reboot forgets applied command ids
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2026-08-06 reporter: temperature events no longer reset delivery backoff
    Protocol §9 grants immediate-attempt privileges to pours and tokens
    only, but the thermo callback used enqueue_'s default reset_backoff, so
    a device with a 60s sensor retried a down server every 60s forever
    instead of backing off to the 5min cap.
2026-08-06 docs, comments: sweep references to removed local mode and legacy pykeg
    - overview, operating-modes, operation, and the offline-behavior heading
    stop naming a `server` mode / local decisions that no longer exist
    - meter and reporter header comments and the sim drop mentions of
    locally decided grants and the removed token status field
    - core comments (hub identity, serial-number validation, tick series)
    cite the v4 protocol -- (device, meter_number) tap identity and
    tick_series -- instead of retired pykeg-era behavior
2026-08-06 sim: pours split and continue across grant boundaries
    When a grant ends or is replaced mid-glass, the firmware ends the pour
    and keeps metering — the sim's pour task just stopped, so receivers
    never saw split-pour traffic (authenticated-pouring §8, cases 3 and 5).
    The pour now runs in segments: a grant boundary finishes the current
    pour and the remaining flow opens a fresh pour_id under whatever covers
    the meter — the new grant, or nobody (a guest pour).
    - tick_series entries become per-interval deltas that sum to the pour's
    ticks (they were cumulative/steps, adding up to about half)
    - gitignore uv.lock (a tooling artifact)
2026-08-06 sim: prompt delivery when healthy, error acks for malformed grants
    - healthy-and-paired now flushes whenever the queue is non-empty, like
    the firmware, so command acks and grant endings no longer sit out the
    heartbeat interval
    - authorize limits are type-checked (numeric, non-negative) and acked
    `error` on garbage instead of crashing the dispatch task or poisoning
    grant state; meter/relay numbers reject booleans (JSON true == 1)
2026-08-06 core: host-testable delivery and auth engines
    The reporter's spec surface (status-code handling, backoff, pairing
    cadence, command dedup/re-acks) and the grant/pour composition
    (adoption, splits, limit trips, pour-before-grant_end ordering) lived
    only in ESPHome-bound components, where the host suite could not reach
    them — the recent temperature-backoff bug is exactly the class that gap
    allows. Both state machines now live in kbcore.
    - kbcore::Delivery owns attempt timing: the status table, exponential
    backoff with cap and reset rules, pairing fast/slow polling, denied
    state, and the command ledger for dedup and re-acks
    - kbcore::AuthEngine owns grant semantics end to end — inventor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
